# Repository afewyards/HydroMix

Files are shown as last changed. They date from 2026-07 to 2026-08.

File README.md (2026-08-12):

# ValveController

A mains-powered, Zigbee-connected controller for a hydronic **3-way mixing valve** — it
regulates the supply-water temperature of a floor heating/cooling system and keeps
regulating **autonomously** if the Zigbee link goes down.

One repo, three parts: a custom KiCad PCB (ESP32-C6), ESP-IDF firmware with a
host-testable control core, and a Zigbee2MQTT converter.

> **Status:** Firmware **1.7.0** released and OTA-deployed (2026-08-11); pure-C control core
> passes host-side unit tests; on-target bring-up of this board per
> [`firmware/BENCH_CHECKLIST.md`](firmware/BENCH_CHECKLIST.md) once assembled.
> PCB rev A — layout complete and **fab-ready** (4-layer, 100 % routed, DRC clean); boards
> ordered 2026-08-12. Personal project.

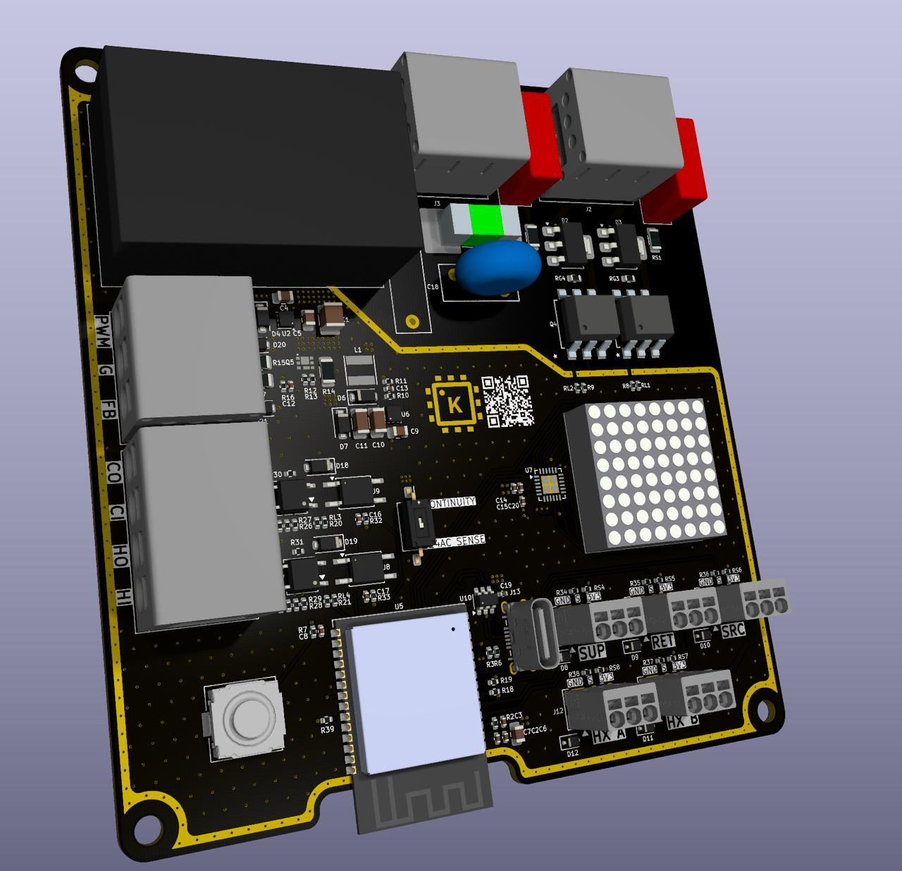
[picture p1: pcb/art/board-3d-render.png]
ValveController 3D render


## What it does

A 3-way valve mixes **SOURCE** water (the hot or cold secondary side of a heat exchanger)
with **RETURN** water from the floor loop to produce **SUPPLY** water at a target
temperature. The controller:

- **Auto-detects mode** (heating / cooling / idle) from a heat-exchanger inlet sensor — the
  host never has to tell it which season it is.
- Regulates supply temperature with a **feed-forward mixing model + PI trim**, hard-bounded
  to floor-safe limits (17–35 °C).
- Drives an ESBE ARA661 230 V 3-point actuator through two solid-state (opto-triac) channels.
- Reads **5× DS18B20** probes (supply, return, source, and two heat-exchanger points) over 1-Wire.
- Exposes everything over **Zigbee** (Router role) for monitoring, tuning, the
  regulation-enable toggle, and **OTA** — with a first-class **Home Assistant / Zigbee2MQTT**
  integration.
- **Runs fully standalone** when Zigbee is unavailable, with a supply "governor" that
  de-escalates any temperature excursion toward safe recirculation regardless of mode.

### ⚠️ The counter-intuitive safety rule

Valve position **0 % = full recirculation** (return water only — thermally harmless).
**100 % = full source** (full hot or cold). Parking the valve "closed" (100 %) would run the
floor at full source temperature and is **dangerous** — so the safe park/idle position is
**mid-travel (~50 %)**, and a resync always drives toward the 0 % end, never the source end.
See the [design spec](docs/superpowers/specs/2026-07-13-firmware-design.md) for the full rationale.

## Hardware

Custom single-board design in KiCad (`pcb/`). Rev A highlights:

| Block | Parts |
|---|---|
| MCU | **ESP32-C6-WROOM-1-N4** (RISC-V, 802.15.4 Zigbee radio, 4 MB flash) |
| Power | 230 V AC → **Mean Well IRM-03-5** (5 V) → **TLV75733** LDO (3.3 V); USB-C 5 V is diode-OR'd in (B5819W) so the board bench-powers and flashes over USB-C with **no mains** |
| Pump interface | **TPS61040** boost to 24 V, driving a **Wilo Para ST 15-7-50 iPWM2** circulator over its PWM/feedback interface |
| Valve drive | 2× channel: **MOC3063S** zero-cross opto-triac → **Z0103MN** triac, switching the 230 V 3-point actuator; RC snubbers + X2 safety caps |
| AUX outputs | 2× **CPC1035N** PhotoMOS channels (24 VAC) with **HCPL-354** loop-open/short detection |
| Mains protection | Varistor (B72210S) + fuse |
| Sensing | 5× **DS18B20** on dedicated 1-Wire connectors (4.7 k pull-ups) |
| I/O | Tactile button, 8×8 LED matrix (**KWM-20881AGB** + **IS31FL3730** driver), **USB-C** — native USB-Serial-JTAG (power, flash, console, JTAG in one port) |
| Connectors | Phoenix pluggable terminal blocks (mains in, actuator) + 5 sensor headers |

Full parts list: [`pcb/ValveController.csv`](pcb/ValveController.csv). Custom 3D component models
live in `pcb/3dmodels/`; `board.step` (repo root) is the assembled-board export.

## Firmware

ESP-IDF 5.5.x, plain C on FreeRTOS. See **[`firmware/README.md`](firmware/README.md)** for the
full build/flash/monitor guide, GPIO map, partition/OTA scheme, console commands, and gestures.

The control logic lives in a **pure-C, IDF-free component** (`firmware/components/ctrl_core/`) so
it compiles and unit-tests on the host (macOS/Linux) before any hardware is involved:

- `feedforward` — exact mixing physics, `(T_set − T_return) / (T_source − T_return)`
- `pi` — PI trim with conditional anti-windup
- `governor` — outermost safety stage; ramps toward recirculation on any supply excursion
- `mode_detect` — heating/cooling/idle with asymmetric dwell + hysteresis
- `degradation` — sensor-fault fallback ladder
- `pos_estimator`, `interlock`, `alarm`, `config_map`

The IDF-side glue (`firmware/main/`) wires that core to hardware: `sensors_hw`, `valve_hw`,
`zigbee`, `ota`, `ui`, `console`, `control_task`, `config`.

Quick start:

```bash
. ~/esp/esp-idf/export.sh
cd firmware
idf.py set-target esp32c6       # first time only
idf.py build
idf.py -p <PORT> flash monitor  # over USB-C; Ctrl+] to exit the monitor
```

Host-side control tests (plain CMake + Unity, no hardware): [`firmware/test_host/`](firmware/test_host/).

## Zigbee / Home Assistant

Router role · manufacturer `Knife` · model `HydroMix`.

- **EP1** — Basic, Identify, On/Off (`water_running` = regulation enable, driven by the host's
  pump/flow automation), Thermostat (local temp = supply; setpoints clamped 17–35 °C; mode is
  auto-detected, host `SystemMode` writes accepted-but-ignored), Analog Output (manual position,
  writable only while regulation is off), OTA client, and a manufacturer-specific cluster
  (`0xFC00`) exposing ~10 tunables, a self-clearing `resync`, and read-only alarm/fault bitmaps.
- **EP2–EP6** — Temperature Measurement for supply, return, source, HX-A, HX-B.

[`z2m/valvectl.mjs`](z2m/valvectl.mjs) is the external Zigbee2MQTT converter (friendly entity names,
tunables as settings, alarms as binary sensors, OTA index). The manufacturer OTA-publishing steps
are documented in the comment header of that file.

## Repository layout

```
ValveController/
├── pcb/                        KiCad project (schematic, board, DRC rules, BOM)
│   ├── 3dmodels/               custom STEP models
│   ├── Kleist2.pretty/         project footprint library
│   └── backups/                local pre-edit snapshots (git-ignored)
├── firmware/                   ESP-IDF application
│   ├── main/                   IDF glue (sensors, valve, zigbee, ota, ui, console)
│   ├── components/ctrl_core/   pure-C control logic (host-testable)
│   └── test_host/              Unity unit tests
├── z2m/valvectl.mjs             Zigbee2MQTT external converter
├── docs/superpowers/           design spec + implementation plan
├── analysis/                   design review reports (schematic, PCB layout)
└── board.step                  assembled-board 3D export
```

## Safety

⚠️ This board switches **230 V AC mains**. All bench work — firmware, sensor reads, triac-drive
verification — can be done on **USB-C power alone**; do not connect mains until the drive channels
are verified per [`firmware/BENCH_CHECKLIST.md`](firmware/BENCH_CHECKLIST.md). And keep the position
convention in mind: the safe idle is **mid-travel**, not "closed."

## Documentation

- [Firmware guide](firmware/README.md) — build, GPIO map, OTA, console, gestures
- [Design spec](docs/superpowers/specs/2026-07-13-firmware-design.md) — control theory, safety, Zigbee model
- [Implementation plan](docs/superpowers/plans/2026-07-13-firmware.md)
- [Bench checklist](firmware/BENCH_CHECKLIST.md)
- [Design review — schematic, 2026-08-11](analysis/design_review_2026-08-11.md)
- [Design review — PCB layout, 2026-08-12](analysis/design_review_2026-08-12_pcb.md) — fab-ready verdict; mains isolation verified against IEC 60664-1

---

Personal project by Thierry Kleist. Released under the [MIT License](LICENSE).

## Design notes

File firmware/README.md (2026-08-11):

# ValveController Firmware

ESP-IDF firmware for the ValveController PCB (ESP32-C6) — a hydronic 3-way mixing
valve controller regulating supply temperature, exposed over Zigbee (Router role)
with OTA, autonomous when the Zigbee link is down.

## 1.7.0 — one diagnostics ring, one clamp table, and `zigbee.c` split four ways

No behaviour change. This release pays down the duplication the 1.6.x debugging work
left behind, so the display/AUX board firmware has clean seams to attach to instead of
three copies of everything to keep in sync.

### Diagnostics: three hand-rolled RTC rings become one

1.6.2 through 1.6.4 added three independent RTC-RAM history mechanisms under time
pressure, one per hypothesis: the 1-Wire tally in `sensors_hw.c`, the per-task
heartbeats in `taskhb.c`, and the Zigbee attribute-write tally in `zigbee.c`. Each
reinvented the same warm/cold-boot detection, 4-deep history shift, and reset-reason
name table — with the two reset-reason tables drifting apart in the process. All three
now sit on one portable `ctrl_core/diag_ring` module (host-tested, zero ESP-IDF
dependencies), and the typed payloads each owner keeps are unchanged. The merged
reset-reason table also **gained** `efuse`, `PWR_GLITCH` and `CPU_LOCKUP`, which neither
of the two originals had. The Zigbee tally's extraction into its own `zigbee_diag.c`
(on the shared ring) was already done in the prior commit; this release is the other
two plus the consolidation.

### Config clamping: three implementations become one table

`clamp_config`, `config_apply_custom` and `tunable_apply` each re-derived the same
per-field min/max/default independently, which is exactly the kind of place a range
quietly drifts between call sites. All three now delegate to a single `SPEC[]` table in
`ctrl_core/config_map.c`, and `config_t` embeds `tunable_cfg_t` directly rather than
duplicating its fields.

`sizeof(config_t) == 76` and every field's offset are pinned by ten `_Static_assert`s,
because `config_load()` tells NVS blob versions apart **by size** — a silent size change
would make every deployed device's stored tuning unreadable and silently revert it to
defaults on next boot. The v1→v2→v3 migration path is untouched and the blob stays
byte-compatible with every device already in the field.

### `zigbee.c`: 984 lines become four files

`zigbee.c` shrinks from 984 to 411 lines, with `zigbee_attrs.c` (169 lines — the
custom-cluster write dispatch), `zigbee_telem.c` (278 lines — telemetry task and
attribute reporting) and `zigbee_diag.c` (137 lines — the write tally, extracted in an
earlier commit of this same release) taking the rest. `zigbee.c` itself keeps only
init, endpoint/cluster registration, and join/steer signal handling. Lock discipline
is unchanged: still exactly 5 `esp_zb_lock_acquire`/`release` pairs, none of them in
the attrs or diag files. This is the seam the display/AUX board's two on/off endpoints
will attach to.

### Image size

712,800 bytes, 64 bytes **smaller** than 1.6.4 (712,864), 62% of the 1.9 MB OTA slot
free either way. Flash was never the constraint here — the Zigbee stack alone is about
half the image, and all of `main/` plus `ctrl_core` together is roughly 3%. This
release traded duplicated logic for a table and a shared module; it did not chase
space, because there was no space problem to chase. (The `-Og`→`-Os` optimisation-level
change is deferred to 1.7.1 as its own single-variable release, shipped alone with
nothing else changed, since it alters code generation on a live heating plant.)

Host suite 19/19.

## 1.6.4 — the console REPL was starving the idle task

Two days of "every temperature probe is dead" were a reboot loop wearing a sensor
costume. Root cause: with no USB host attached, the console REPL's reads return
immediately instead of blocking, so its line-editing loop free-runs. It sits at a
priority above the idle task (0) and below the app tasks (4-6), so every
watchdog-subscribed app task kept feeding normally while the idle task never got
scheduled — and the idle task is a subscriber
(`CONFIG_ESP_TASK_WDT_CHECK_IDLE_TASK_CPU0=y`). 30 s later, `ESP_RST_TASK_WDT`. Forever,
every ~40 s, but **only when no USB host was attached**.

That is the whole illusion. Probes boot latched-faulted for ~30 s by design
(`SENSOR_CLEAR_AFTER` = 3 sweeps at 10 s), and the board reset at ~40 s. So the only
value that ever reached the coordinator was the ZCL invalid sentinel 0x8000 — five
simultaneously dead probes, over and over, on a plant whose probes were perfect.

`console_start()` now waits for `usb_serial_jtag_is_connected()` in a task that blocks on
`vTaskDelay` before creating the REPL. Verified live: mains-only cold boot, temperatures
flowing continuously past the 40 s mark and `mode` back to `cooling` — the plant
regulating again for the first time since 2026-08-10.

### What was innocent

Worth recording, because each was suspected in turn and none was at fault: the DS18B20
probes and the 1-Wire bus (zero read failures in every tally, ever), the temperature
attribute writes (`ok`, `mism=0`, table reading back real values), the Zigbee reporting
path, the power supply, and 1.6.1's feedforward change — which altered only mixing-law
maths and was blamed purely because the outage began at its OTA reboot. The OTA reboot
was the trigger only in the sense that it was the first boot with no USB attached.

### The observability trap, which cost more than the bug

Reaching this board's console takes two resets: plugging the cable in is one, opening the
port is another. Worse, attaching USB is *also* the intervention that stops the fault. So
a one-deep "previous run" record always describes the run your own reset ended, never the
run the fault ended — the measurement consumes its own evidence.

That trap was hit three times in one investigation: it destroyed the 1-Wire tally for the
13 h outage, then the first attribute-write tally, then the first heartbeat record. Every
RTC diagnostic now keeps **4 runs**, tagged with a boot sequence number, and where it
matters labelled with how each run ended (`boot=TASK_WDT`). Two resets can no longer reach
the run under investigation.

### Diagnostics added

- `stats` — 1-Wire failure tallies per reason (`rmt`/`reset`/`write`/`read`/`crc`/`por85`), 4 runs deep.
- `zbtemp` — per-endpoint attribute-write ok/fail/status, plus a read-back of what the ZCL
  table actually holds, with ticks/sweeps/faults and the reset reason per run.
- `hb` — per-task heartbeat ages, each run labelled by how it died. This is what named the
  culprit: every app task fed on schedule right up to the reset, leaving the idle task as
  the only possible starved subscriber.

Host suite 17/17.

## 1.6.2 — a dead sensor sweep can no longer hide as five dead probes

On 2026-08-10 the plant sat parked for 13 h after an OTA to 1.6.1. All five probe
endpoints published the ZCL invalid sentinel (0x8000) continuously from 19:11:32Z —
the moment of the post-OTA reboot — until a reset was forced by hand the next
morning. Everything else looked healthy: the device stayed joined, answered reads,
accepted valve commands, and the temperatures had been reporting normally right up
to 19:10:53Z with the plant actively cooling.

The 1-Wire bus was never the problem. `stats` after the reset showed **zero read
failures of any kind** — no `rmt`, no `reset`, no `crc`, on any probe — and every
probe returned a plausible temperature immediately.

**Superseded by 1.6.4: neither hypothesis below was right.** The outage was a
`TASK_WDT` reboot loop every ~40 s caused by the console REPL starving the idle task
whenever no USB host was attached; the probes never failed at all. The two candidates
recorded here are kept because the reasoning that produced them is instructive, not
because either was correct.

At the time the root cause was not identified, and the evidence that would have named it
was gone: the per-reason failure tally lived in RTC RAM and held only one previous run,
so plugging in the console cable to read it overwrote the very run under investigation.
Two mechanisms then looked consistent with everything observed:

- the 1-Wire/RMT driver wedged, failing every read (would have logged a `sweep N
  failed: …=rmt` line every 10 s);
- the sweep task never ran at all (would have logged nothing whatsoever).

Both were excluded once the reboot loop was found: every tally showed zero read failures
and normal sweep counts. The changes in 1.6.2 remain worth keeping on their own merits —
they close a real gap in which a dead sweep is indistinguishable from five dead probes —
but they did not fix this outage.

What made a 13 h silent outage possible is a gap that IS identified, and is fixed here.
`sensors_start()` seeds every probe latched-faulted on purpose, so a sweep task that
dies — or never starts — is indistinguishable from five simultaneously dead probes,
permanently. Nothing else caught it either: the staleness guard in
`sensors_fill_faults()` is skipped while `last_ok_ms == 0`, and a task that never ran
never subscribed to the task WDT, so the watchdog had nothing to time out on. The
plant parked, which is correct, and said nothing, which is not.

- **Sweep liveness is now tracked per iteration**, not per successful read — a sweep
  that runs and fails everything is a plant problem, one that stops running is a board
  problem, and only this separates them. Surfaced as `FAULT_BIT_SWEEP` (bit 5), so
  `fault_bitmap` reads 0x3f for a dead sweep against 0x1f for five dead probes.
- **Bounded self-heal.** 120 s of dead sweep triggers a reset, up to 3 consecutive
  attempts, after which the board stays up and parked with the bit raised rather than
  reboot-looping a live household plant. The budget is restored after 10 min of healthy
  sweeping. The counter lives in RTC RAM so it outlives the reset it is counting.
- **Every `xTaskCreate` return is now checked.** All of them were unchecked, so a
  failed create was silent and permanent — a failure mode that produces exactly the
  observed signature. The sensor, valve, control, Zigbee and telemetry tasks abort
  (panic → reset → rollback on an unvalidated image); the LED and button tasks only
  log, since taking a working plant down over a dead status LED is the larger fault.

Host suite 17/17.

## 1.6.1 — the feedforward no longer picks a rail on probe noise

Diagnosed from live GF-HydroMix history over 2026-08-07..10. The cooling plant lost
output for ~4.5 h on 08-08 (01:40–06:30Z): source, supply, return and hx_b all
equilibrated at ~21 °C and hx_a — normally the coldest point at ~15 °C — rose to
23.4 °C. With `t_src ≈ t_ret` the mixing law had no authority, and dT(return−source)
sat inside ±0.05 K for the whole window.

The feedforward computes `clamp((t_set − t_ret)/(t_src − t_ret) · 100, 0, 100)`.
`want` cannot change sign within a mode, so at low authority the sign of the
denominator alone decided which rail the output clamped to. 1.5.1 limited the
denominator's magnitude to the authority floor but kept its measured sign, which
left a step discontinuity at `denom = 0` the width of the entire output range: at
t_ret 20.9 / t_set 18.5, t_src 20.89 commanded 100 % and 20.91 commanded 0 % — two
readings 0.02 K apart, well inside DS18B20 pair-to-pair disagreement.

Live, the valve chattered rail to rail with the 180 s output EMA turning it into a
sawtooth: **2906 % of travel on 08-08 against ~750 % on each neighbouring day**, and
six end-stop resyncs between 02:34 and 09:51. Closing was also the self-defeating
move — at the measured −0.041 K/% coupling, shutting the valve drives `t_src` further
past `t_ret`, deepening the condition that closed it.

1.6.1 blends the two available answers instead of switching between them: the
measured-sign answer, and the demand direction that restores authority, weighted by
`w = |denom| / floor` and only inside the band. Where the source is on the useful
side both terms are the same expression, so the healthy operating band is unchanged
bit for bit; only near-zero readings, where the sign is noise, are reinterpreted. A
source genuinely past the floor — the unseated-probe case — still clamps to 0 %.

Continuity sweep, worst adjacent output jump per 0.05 K of probe movement: **100.00
→ 2.50**, the blend ramp's own maximum slope.

The demand-direction fallback rests on the source↔valve coupling being negative,
which is a property of the **fixed-speed pump** — valve position is the only thing
modulating source-branch flow, so starvation dominates. A pump that modulates flow
independently invalidates the premise; re-measure open-loop before carrying it over.
See `FF_COUPLING_PCT_K` in `feedforward.h`.

Known-unfixed, found in the same investigation: `travel_since_resync` is written
every 10 s by `zigbee_push_status()` and is declared reportable, but
`configure_reporting_on_join()` never arms a reporting record for it — so it only
ever reaches the coordinator on an explicit read at `configure()` time and reads
frozen in HA.

## 1.6.0 — resync can now target the source end, gated by comfort

Diagnosed from 19 h of live GF-HydroMix telemetry (16:29Z–01:47Z, 2026-08-05): in the
current cooling regime the valve regulates at 85–100 %, so every position resync —
previously always a drive to the 0 %/recirculation end-stop — was a ~200 % round trip
with ~3 min of forced recirc and a ~2 K supply excursion. Three such events tripped
in that window, preferentially right after source cold slugs, i.e. exactly when the
plant was already disturbed. "Valve goes to 0 for no reason" was the live symptom.

- **A resync may now target the 100 %-source end-stop** when the valve is already near
  it and a comfort gate passes, instead of unconditionally driving to recirc. New pure
  module `ctrl_core/resync_policy.c` decides the end each cycle:
  - position < `RESYNC_NEAR_END_PCT` (50 %) → recirc-end immediately (cheap; the mix
    is mostly recirc already).
  - position ≥ 50 % and the gate passes → source-end.
  - position ≥ 50 % and the gate fails → deferred, re-checked every control cycle:
    source-end the instant the gate passes, or recirc-end after
    `RESYNC_DEFER_MAX_MS` (30 min) — whichever comes first. Position dropping below
    50 % while deferring also forces recirc-end immediately, since it just got cheap.
  - The accumulated-travel / reversal counters that trigger a resync keep accumulating
    through deferral; they only reset on resync completion, unchanged.
- **The comfort gate** (`resync_gate_eval()`, computed once per cycle in `control_step`
  and published to `valve_hw` via `valve_note_resync_gate()`) requires: mode is HEATING
  or COOLING, the source probe is unfaulted, `|t_src − setpoint| ≤ RESYNC_SRC_GATE_K`
  (2.0 K), and `t_src` sits inside the governor band with a `RESYNC_GATE_GOV_MARGIN_K`
  (1.0 K) margin on both sides. A dew-guard-raised setpoint tightens the gate along
  with it automatically. All four thresholds are compile-time constants — no new
  Zigbee tunables.
- **Mid-stroke abort:** resync ignores regulation targets while driving, so a
  source-end stroke that starts at the edge of a cold slug can carry `t_src` below the
  governor band with nothing to stop it. If the source leaves the raw governor band
  during a source-end stroke, the stroke aborts and restarts as a fresh full
  recirc-end stroke — its stall deadline extended by the interlock's reversal
  blackout (`INTERLOCK_MIN_PULSE_MS + INTERLOCK_DEAD_TIME_MS +
  INTERLOCK_ANTI_DITHER_MS`) so the deadline accounts for the pulse-finish,
  dead-time and anti-dither the interlock imposes before the reversed drive actually
  starts. Recirc-end strokes never abort. Worst case equals pre-1.6.0 behavior; never
  worse.
- **Boot resyncs and manual resyncs (console `resync` / Z2M switch) stay forced
  recirc-end**, unconditionally — sensors boot latched-faulted, and bench use wants a
  predictable end-stop. A manual resync requested while an autonomous source-end
  stroke is already driving is **latched, not dropped**: `valve_task` only consumes
  the pending manual-resync flag once the drive returns to idle, so it fires as a
  forced recirc-end stroke the moment the in-flight autonomous stroke completes.
- Stroke duration stays `travel_time_s × RESYNC_STALL_MULT` in both directions (plus
  the abort extension above) — drift is why a resync happens at all, so no
  distance-based shortening. `pos_est_resync_done()` now takes the end-stop seed (0.0
  recirc / 100.0 source) instead of always seeding 0.
- This deliberately supersedes the 2026-07-13 "resync only toward the
  0 %/recirculation end-stop" rule and the `NEVER toward source` comment it left in
  `valve_hw.c`. The original rationale — 100 % source is the dangerous end — now
  holds via the gate, the governor-band bound and the mid-stroke abort, not a blanket
  prohibition.
- Not yet Zigbee-exposed: resync events, the chosen end, and gate state publish
  nowhere — pairs with the still-open `ff.frozen`/authority-floor telemetry gap from
  1.5.1, next release.

New constants (`components/ctrl_core/include/ctrl_core/resync_policy.h`):
`RESYNC_SRC_GATE_K` 2.0 K, `RESYNC_GATE_GOV_MARGIN_K` 1.0 K, `RESYNC_DEFER_MAX_MS`
1 800 000 (30 min), `RESYNC_NEAR_END_PCT` 50.0 %.

Design spec: `docs/superpowers/specs/2026-08-05-gated-bidirectional-resync-design.md`.

Suite 17/17, 119 tests. Build clean, 63 % OTA headroom, embedded app version verified
1.6.0.

## 1.5.1 — the authority floor had the wrong sign, and the freeze latched the valve

**1.5.0 broke cooling on the live plant.** On 2026-08-04 the valve sat at 55.7 % for 92
minutes while supply ran 2.6–2.75 K above an 18.5 °C setpoint and the house stopped being
cooled. Root-caused from 869 Z2M samples (09:00–10:33).

### What went wrong

Three things compounded:

1. **A freeze disconnected the whole controller, not just the integrator.** `pi.c`'s
   `if (freeze) return ctrl_clampf(pos_ff, …)` discards **both** P and I, and `control.c`
   passed `freeze_pi || ff.frozen`. So a low-authority FF handed the valve a bare frozen
   constant and ran open-loop — while `t_supply`, a perfectly valid measurement, was ignored.
2. **The floor was placed inside the plant's normal operating range.** At the live 18.5 °C
   setpoint the derived floor was `sqrt(2.7·100·0.065)` = 4.19, clamped to the 4.0 K ceiling.
   Measured `|t_src − t_ret|` runs **0.07–4.75 K, mean 1.89** → **87 % of samples treated as
   no-authority.** The valve moved on exactly 5 occasions in 92 min, *all* of them inside the
   one window where `|denom|` crossed 4.00.
3. **The escape hatch was a no-op.** `if (ff.park_requested) target = in->valve_pos;` commands
   exactly what the freeze already commands. 1.5.0 correctly identified that the old open-loop
   park to `park_pos` was harmful, but deleted the only thing that broke the latch.

And the latch is self-reinforcing: a pinned valve starves the source branch, a starved branch
stops being cooled, `t_src` drifts toward `t_ret`, `|denom|` shrinks further. It reached
**0.07 K**. There was no exit.

### The coupling sign was inverted

`FF_COUPLING_PCT_K = +0.0654 K/%` came from a 20 h **closed-loop** fit at only r = +0.49,
taken while the HX primary itself drifted 14.25 → 16.93 °C. The controller opens the valve
*because* the primary warmed, so valve % and `t_source` both track `hx_a` and correlate
positively with no causal content — a confound.

The open-loop measurement (valve held manually at full source, primary flat to within
0.19 K) gives the **opposite** sign: `t_src` fell 20.87 → 19.06 °C over ~44 % of travel,
about **−0.041 K/%**. More source flow *cools* the source; flow starvation dominates the
textbook rise in HX approach.

That inverts the derivation, not just its magnitude. `ff_authority_floor()` computes a loop
gain **magnitude** and treats |G| > 1 as runaway — but sign decides whether feedback
diverges. With the true negative coupling, opening the valve cools the source, *grows*
`|denom|` and backs the valve off: negative feedback, self-limiting. **The floor guarded a
runaway that cannot happen in this plant, while manufacturing a real latch.**

### The fix

- **`ff_step` now LIMITS the denominator instead of abandoning the division.** Output stays
  live, bounded, continuous and correctly signed, and — because the coupling is negative — it
  points the valve the way that *restores* authority. Saturating toward the source is the
  correct response to a converging source, not an error to suppress. A source on the wrong
  side of `t_ret` still clamps to 0; `denom == 0` falls back to the demand direction.
- **`ff.frozen` no longer freezes the PI.** Only `resync_active` does, where the valve is
  being driven to an end stop and the output is moot anyway.
- **`FF_COUPLING_PCT_K` → 0**, so the floor is a fixed 2 K numerical guard. Do *not* re-enable
  it from another closed-loop fit — it needs an open-loop step test (park the valve at 2–3
  positions ≥ 20 min each with the controller out of the loop).
- **`FF_OUT_TAU_S` 900 → 180 s.** 900 s was ~7.5× the valve travel time. The travel reduction
  it was credited with came mostly from the freeze pinning the valve: at 180 s the 1.5.0 sim
  is still frozen 100 % of the time with zero travel.
- **`park_requested` / `FF_NO_AUTHORITY_PARK_DWELL_MS` removed**, along with `last_valid` /
  `freezing` / `frozen_since_ms` — all dead once the denominator is limited. `water_running`
  OFF, `MODE_IDLE` and `CTRL_PARK` parks are untouched; those are real safety parks.

### The test that blessed the bug

`test_hx_feedback.c`'s headline gate was `new.travel < 0.50 × old.travel` — *"the valve moved
less."* Re-run on its own plant at the shipped coupling, 1.5.0 gives **travel 0.0 %, frozen
100 %, pinned at 48.3 %, supply 1.0 K warm — and it PASSED.** Its supply guards passed only
because the baseline it compared against was itself railed at 98.3 % with +2.65 K error.

**A latched valve trivially wins a travel-reduction gate.** Travel is now bounded on *both*
sides and tracking error is capped absolutely, not relative to a broken baseline. The plant
also carries the measured negative sign, and `test_ff_recovery.c` is new: it starts in the
observed starved state and fails on 1.5.0 (49.2 %, travel 0, +2.33 K) while 1.5.1 reaches
95.8 % — the analytic optimum is 95.7 % — at −0.01 K.

Suite 16/16, 105 tests. Build clean, 63 % OTA headroom, embedded app version verified 1.5.1.
Flashed over USB 2026-08-04. **Still open:** `ff.frozen` and `authority_floor_k` are published
nowhere, which is why 87 % frozen was invisible in HA and a human had to notice the house was
warm. Exposing them needs a Zigbee attribute plus a converter deploy — next release.

## 1.5.0 — feedforward vs. the HX approach coupling; no more open-loop parks

Diagnosed from 20 h of live GF-HydroMix cooling telemetry (2026-08-03), after the valve
began hunting once the cooling setpoint moved from 20 °C toward 19 °C.

> **Version note.** The 2026-08-03 bench build shipped everything below but still
> self-identified as **1.4.0**, because `version.txt` was never bumped — a different
> failure from the 1.3.x `PROJECT_VER` CMake-cache trap, with the same symptom. When you
> need to know which source a flashed image really is, check for a version-unique symbol
> (`nm build/valvecontroller.elf | grep ff_authority_floor`) rather than trusting the
> reported version, `version.txt`, or Z2M's `installed_version`.

### The 60 s park was worse than the freeze it escalated (2026-08-04)

Live follow-up on the build above: the valve kept dropping to ~22 % for ~90 s at a time.
Not a spike and not a reporting artefact — a *commanded* move, every step exactly
8.3 %/10 s (full slew at `travel_time_s 120`), bottoming just short of `park_pos 20`
because `valve_deadband_pct 2` stops the motor within 2 % of target.

- **Cause: the derived floor made the freeze reachable, and the freeze escalated to a
  park.** The floor tracks the setpoint, so moving from 20 °C to 19 °C raised it from
  2.79 K to **3.51 K** (at `t_ret ≈ 20.9`), while the plant's live `|t_src − t_ret|` runs
  3.31…6.75 K — it dips under 3.51 K but never under the old fixed 2.0 K. Replaying the
  freeze predicate over 3 h 13 m of telemetry: **exactly two freezes ≥ the 60 s dwell,
  exactly two observed parks, zero false positives in 2316 samples.** So the fix for
  hunting at 19 °C is what introduced parking at 19 °C.
- **`park_requested` now holds position instead of driving `park_pos`, and no longer
  resets the PI.** Parking is open-loop, and in cooling it *raises* supply temp (+0.7 K
  measured per event) — it manufactures the disturbance the loop then has to undo. A
  freeze is already stable on its own: the FF holds `last_valid`. Recovery from a hold
  resumes on the integrator it left, rather than rebuilding from zero.
- **`FF_NO_AUTHORITY_PARK_DWELL_MS` 60 s → 600 s**, demoted to a backstop for a genuinely
  stuck plant now that the sustained case no longer parks.
- The `water_running` OFF, `MODE_IDLE`, and `CTRL_PARK` degradation parks are unchanged —
  those are real safety parks. The governor still applies after the hold.

### Investigated and REJECTED: splitting the PI deadband off the integral path

Supply sits at **+0.39 K** against a 19 °C setpoint (user-visible as "19.5 instead of
19"); the parks above account for only +0.025 K of it. `pi_step()` zeroes `e_eff` inside
±`deadband_k` and uses it for **both** the proportional and integral paths, so on paper
every point in `[setpoint − deadband_k, setpoint + deadband_k]` is an equilibrium with a
frozen integrator — a textbook permanent offset. The live minimum over a 3 h capture was
exactly **18.75** = 19 − 0.25, sitting precisely on the deadband edge, with 52 % of
samples inside the band. That looked conclusive.

**It did not survive simulation, and the change was reverted.** `test_lagsim`'s FOPDT
loop, 6 h per run, comparing the shipped code against a variant whose integrator runs on
true error, plus two intermediate variants (integral deadband at 0.4× and 0.6× the
proportional one):

- At **4 of the 5 corners the offset is identical to three decimal places** across every
  variant and every `ki` in 0.9…0.2. The residual offsets there (+0.17, −0.50, +0.17,
  −0.05) are plant and valve-quantisation artifacts the integral path cannot influence.
- At **θ=40 / τ=60 removing the integral deadband is materially worse**: the loop settles
  at **−0.94 K** where the shipped code sits at **+0.06 K**. That is integral windup
  through the 40 s deadtime — the deadband is acting as a brake against it, not merely
  buying the offset. This is the corner closest to the real GF-HydroMix plant.
- It also breaks the existing `new_pp < 0.8` gate at the shipped `ki=0.9` (1.21 K) and
  would have needed a `ki` retune to 0.5 purely to compensate.

Why the live signature misleads: in the lagsim's geometry (`T_SRC` 45 / `T_RET` 27, an
18 K span) 2 % of valve travel is worth ~0.54 K of supply, which swamps the 0.25 K
deadband. On the real plant the span is only ~4.8 K, so 2 % of travel is ~0.13 K and the
deadband edge becomes visible in the data — but visible is not the same as binding, and
no variant of relaxing it actually moved the number.

**If the offset is worth chasing, do it with the existing `pi_deadband_k` tunable
(custom-cluster 0x000F, live-writable over Zigbee) as a reversible experiment on the real
plant — not with a structural change to the controller.** Note the 1.4.0 five-corner
sweep already found ripple *non-monotonic* in `pi_deadband_k` between 0.15 and 0.25
(limit-cycle regime hopping), so do not bisect it; test discrete values and watch.

- **The FF was driving its own denominator.** `ff_step()` inverts a mixing law that treats
  `t_source` as an independent input. On a plate HX fed by a fixed primary it is not:
  opening the mixing valve raises *secondary* flow, collapses the HX approach, and warms
  `t_source` — the quantity `pos_ff = (t_set − t_ret)/(t_src − t_ret)` divides by.
  Regressed live: **d(t_source)/d(valve %) = +0.0654 K/%** (r = +0.49), approach sweeping
  −0.57…+6.25 K while the primary side (`hx_a`) stayed inside 14.25…16.93 °C. Net effect:
  `t_source` swung **7.81 K p2p, 3× its own primary**, and the valve swung 98.5 % p2p.
  Supply itself was never the problem (sd 0.37 K) — valve travel was.
- **Authority floor is now derived from the setpoint** instead of the fixed
  `FF_MIN_AUTHORITY_K 2.0`. Chaining the coupling through the mixing law gives loop gain
  `G = |t_ret − t_set| · 100 · coupling / denom²`, so `G = 1` at
  `denom = sqrt(|t_ret − t_set| · 100 · coupling)`. That tracks the setpoint, which is
  exactly what a constant gets wrong: at `t_ret ≈ 21.2` the floor is **2.80 K at a 20 °C
  setpoint but 3.79 K at 19 °C**. Clamped to `[FF_AUTHORITY_MIN_K 2.0,
  FF_AUTHORITY_MAX_K 4.0]` — past ~4 K the freeze stops being free (measured share of
  flowing time spent frozen: 2.0 K → 3.0 %, 2.8 K → 3.6 %, 3.8 K → 6.4 %, but
  4.6 K → 17.7 % in runs long enough for the 60 s park dwell to dominate).
- **The FF output carries a 900 s EMA** (`FF_OUT_TAU_S`), applied to `pos_ff`, *not* to
  `t_source`/`t_return`. The mixing law divides by `(t_src − t_ret)`, so filtering the
  inputs and then dividing does not land where dividing and then filtering does — and
  with the denominator swinging several K that gap is not second-order. Filtering after
  the division also leaves the low-authority test on the live reading, so a collapse in
  authority is still caught the instant it happens. This is the *secondary* fix: the
  floor is what keeps the FF out of the region where it fights itself; the EMA only stops
  the motor chasing the ripple that remains.
- **A zeroed `ff_cfg_t` degrades to the pre-1.5.0 fixed 2 K floor, not to no floor.**
  `control_cfg_t` is brace-initialised in several places (including `test_control.c`), and
  a zero `auth_max_k` would otherwise disable the low-authority freeze altogether.
- `ff_reseed()` on a resync falling edge drops the output filter but keeps `last_valid`;
  `ff_mode_change()` drops both, since heating and cooling put `pos_ff` on opposite sides
  of `t_ret`.
- Not Zigbee tunables. They live in `ff_cfg_t` (filled by `ff_cfg_defaults()` in
  `control_task.c`) purely so the host tests can drive old and new behaviour through one
  code path — and so promoting any of them to a custom-cluster attribute later is a small
  diff. **No NVS bump**, so no downgrade hazard this time.

`test_hx_feedback.c` is the new closed-loop regression: the plant reproduces the measured
coupling, and the coefficient is swept {0.04, 0.0654, 0.09} because 0.0654 is a
closed-loop estimate at only r = 0.49. Across that sweep, valve travel falls to
**0.28–0.39×** and source p2p to **0.40–0.51×**, while supply p2p and mean offset improve
at the two stiffer couplings. `test_lagsim.c` is unaffected by construction — its source,
return and setpoint are constant, so the EMA reseeds on the first step and then holds.

## 1.4.0 — valve deadband tunable + RunningMode push

- **Motor stop deadband is now a runtime Zigbee tunable** (`0x0012 valve_deadband_pct`,
  float %, custom cluster `0xFC00`, same read/write/NVS-persist machinery as the other
  tunables). Was a compile-time `#define DEADBAND_PCT 2.0f` in `valve_hw.c`.
  **BEHAVIOR CHANGE:** the shipped default is now 1.0 % *at `travel_time_s` ≥ 120 s*
  (was effectively 2.0 % on every device before this release, regardless of
  `travel_time_s`) — halved because at `kp=2.8 %/K` that's ≈±0.36 K of supply error
  before the motor reacts, and the existing 30 s transit hold + 0.25 K supply-move
  release already suppress oscillation at the tighter band. Below `travel_time_s=120`
  this is NOT a straight halving: `clamp_config()` raises the migrated default up to
  the travel-derived floor (below), so a device already tuned to `travel_time_s=60`
  lands at 2.0 % (unchanged) and one at `travel_time_s=30` lands at 4.0 % (doubled).
  Clamped to `[max(0.2, floor), 5.0]`, where `floor` is derived from the interlock's
  minimum drive pulse and the current `travel_time_s` (`1.2 × (INTERLOCK_MIN_PULSE_MS /
  1000) × 100 / (2 × travel_time_s)` — ≈1.0 % at 120 s, 2.0 % at 60 s, 0.2 % at 600 s):
  a constant floor below this lets a short travel time turn every drive pulse into a
  full band crossing, limit-cycling the motor. Writing `travel_time_s` re-clamps
  `valve_deadband_pct` against the new floor as a side effect (shortening travel can
  raise the floor above an already-set deadband) — both the Zigbee attribute store and
  NVS reflect the adjusted value.
- **`pi_deadband_k` (`0x000F`) stays at its 0.25 K default.** A lower value (0.15) was
  considered alongside the valve-deadband work above, but a closed-loop sweep of
  {0.15, 0.20, 0.22, 0.25} against `test_lagsim.c`'s dead-time/lag robustness matrix
  found only 0.25 clears every corner's convergence/ripple gate — 0.25 ships unchanged.
- **NVS config migrates v2 → v3** (`CONFIG_VERSION` 2 → 3) to add `valve_deadband_pct`
  without wiping existing tunables: a 1.3.x-sized blob is read field-by-field, the new
  field defaults to 1.0, and the blob is re-saved at the new size/version. **Downgrading
  to ≤1.3.1 after this release wipes the config** — the old firmware's loader only
  recognizes its own (smaller) blob size and falls back to defaults for anything else.
- **Thermostat `RunningMode` (`0x001E`) now pushes an explicit unsolicited report** on
  every change, and once on every (re)join. This is a belt-and-suspenders addition, NOT
  the root-cause fix for the 6 h-stale `mode` sensor observed live: the actual cause was
  that EP1's `hvacThermostat` cluster was never bound in the first place (live
  binding-table inspection showed EP1 bound for `genOnOff`/`genAnalogOutput` only), so
  neither the passive ZCL reporting-engine config *nor* this new explicit push has
  anywhere to send a report without a binding. The root-cause fix is converter-side —
  `z2m/valvectl.mjs`'s `configure()` now binds `hvacThermostat` — and this firmware push
  only helps once that binding exists.

## 1.3.1 — Zigbee-writable setpoints

- **heat_setpoint / cool_setpoint moved to the custom cluster** (attrs `0x0010`/`0x0011`,
  float °C, clamped 17–35, NaN-rejected, echoed back, NVS-persisted — same machinery as
  the other tunables). The standard Thermostat cluster rejects every setpoint write on
  this device with `INVALID_VALUE`: ZBOSS enforces the ZCL single-zone invariant
  `heat ≤ cool − deadband`, which the device's independent seasonal targets (heat 35 /
  cool 18) deliberately violate. The thermostat cluster's `OccupiedHeating/CoolingSetpoint`
  are effectively static boot defaults: the firmware attempts a mirror write on every
  custom-cluster setpoint change, but ZBOSS vetoes local thermostat setpoint stores under
  the same deadband rule (verified on-air 2026-07-31, `check=false` notwithstanding), so
  reads of the standard attributes do NOT reflect the live targets — use the custom
  attrs. `z2m/valvectl.mjs` exposes both as `heat_setpoint` / `cool_setpoint` numbers
  and no longer attempts thermostat-cluster writes.

## 1.3.0 — review-findings release

Safety and correctness fixes from the 2026-07-31 firmware review:

- **water_running now survives a reboot.** Persisted in its own NVS key (`valvectl/water`,
  outside the cfg blob, so no `CONFIG_VERSION` bump) and used to seed the OnOff attribute
  at endpoint build. Previously every boot forced regulation ON while HA read OFF. Absent
  key ⇒ OFF (parks at `park_pos`). A factory reset therefore boots OFF.
- **Faulted probes publish the ZCL invalid sentinel `0x8000`** instead of a frozen
  last-good value, on both Temperature Measurement `MeasuredValue` and Thermostat
  `LocalTemperature`. `z2m/valvectl.mjs` maps it to `null`.
- **The sensor sweep is watchdogged**, and any reading older than 35 s (3 sweep periods
  + slack) is reported faulted regardless of latch state — a wedged sweep now degrades
  control to park instead of integrating frozen data. `sensors_fill_faults()` takes one
  coherent locked snapshot.
- **OTA validation gate moved outside the watchdog window:** 12 control cycles (~110 s)
  instead of 3 (~20 s), extracted to `ctrl_core/ota_gate.c` and host-tested.
- **Fault-streak decay requires 3 consecutive good reads** (break-even 25 % failure rate,
  was 33 %) — a probe failing a third of its sweeps now latches.
- **Thermostat setpoint writes echo the clamped value back** to the attribute store, and
  only write NVS when the value actually changed.
- **Cooling dew guard triggers on 30 min of traffic silence** rather than a ZDO link-down
  signal, which a silently dead coordinator never sends.
- **Supply freeze alarm is held while the supply probe is faulted** (no false latch on a
  BSS-zero reading, no false clear on a frozen in-band one).
- `travel_time_s` is latched with `direction_swap`, so a mid-stroke write cannot corrupt
  the position estimate; a short first OTA payload block now aborts loudly.

## Prerequisites

- **ESP-IDF v5.5.4**, installed at `~/esp/esp-idf` on this machine. Activate it in
  every new shell before running `idf.py`:
  ```
  . ~/esp/esp-idf/export.sh
  ```
- Target chip: **esp32c6**. If starting from a clean checkout (or after switching
  IDF versions), set the target once:
  ```
  cd firmware
  idf.py set-target esp32c6
  ```
- USB-C cable to the board's native USB-Serial-JTAG port (GPIO12/13) — this is
  used for flashing, the console, and JTAG. **No separate USB-to-serial adapter
  needed.**

## Build / flash / monitor

```
cd firmware
idf.py build
idf.py -p <PORT> flash monitor
```

The first `idf.py build` (or any build after an `idf_component.yml` change)
fetches managed components (`espressif/onewire_bus`, `espressif/esp-zigbee-lib`,
`espressif/esp-zboss-lib`) — this can take a few minutes and needs network
access. Resolved versions are pinned in `firmware/dependencies.lock` (currently
esp-zigbee-lib 1.6.8, esp-zboss-lib 1.6.4, onewire_bus 1.1.1).

Exit the serial monitor with `Ctrl+]`.

## Partition table and OTA

`firmware/partitions.csv` (4 MB flash, `CONFIG_ESPTOOLPY_FLASHSIZE_4MB=y`):

| Name | Type | SubType | Offset | Size |
|---|---|---|---|---|
| `nvs` | data | nvs | 0x9000 | 0x6000 |
| `otadata` | data | ota | 0xf000 | 0x2000 |
| `phy_init` | data | phy | 0x11000 | 0x1000 |
| `ota_0` | app | ota_0 | 0x20000 | 0x1D0000 (~1.81 MB) |
| `ota_1` | app | ota_1 | 0x1F0000 | 0x1D0000 (~1.81 MB) |
| `zb_storage` | data | fat | 0x3C0000 | 0x38000 |
| `zb_fct` | data | fat | 0x3F8000 | 0x1000 |

(Note: the OTA-data partition is named `otadata`, not `ota_data`.)

Two-slot OTA with `CONFIG_BOOTLOADER_APP_ROLLBACK_ENABLE=y`. The actual gating
logic lives in `firmware/main/ota.c`:

- On boot, `ota_init()` checks whether the running image is still
  `ESP_OTA_IMG_PENDING_VERIFY` (i.e. it was just flashed via OTA and hasn't been
  validated yet).
- The image is marked valid — cancelling any pending rollback — once
  `ota_note_joined()` (Zigbee rejoined, called from `zigbee_on_join()` in
  `app_main.c`) **and** `ota_note_good_sweep()` have both fired.
  `ota_note_good_sweep()` is called from `control_task.c` on either of:
  1. a control cycle completing with no sensor faults, checked every cycle
     (fast path), or
  2. `OTA_GATE_CYCLES` (12) completed control cycles regardless of sensor faults —
     sensor faults are a plant-wiring property, not an image property. 12 cycles at
     the 10 s control period is ~110 s, deliberately **longer** than the 30 s task
     watchdog timeout (`CONFIG_ESP_TASK_WDT_TIMEOUT_S=30`, panic on): a control task
     that hangs trips the watchdog and reboots — rolling back — *before* this gate
     could ever validate the image. (1.2.1 used 3 cycles ≈ 20 s, which fired inside
     the watchdog window and so proved nothing.)

  As a last resort, a bounded 10-minute fallback timer (started at rejoin)
  validates unconditionally if neither path above has fired yet.

  If the new image never reaches validation by any of these paths, the
  bootloader rolls back to the previous image on the next reset.

**Publishing an OTA update via Zigbee2MQTT:** there is no cloud OTA index entry
for this private manufacturer code. The process (documented in comments at the
top of `z2m/valvectl.mjs`) is: build `firmware/build/valvecontroller.bin` →
wrap it into a Zigbee OTA image (`.ota`) with the ZCL OTA header (manufacturer
code, image type, file version) → host the `.ota` file somewhere Z2M can read
it → add an entry (`modelId`, `url`, `fileVersion`) to Z2M's local OTA index
config.

## Boot-safety invariant

`triacs_safe_low()` is the **literal first statement** in `app_main()`
(`firmware/main/app_main.c`) — before NVS, before anything else. It configures
GPIO2 and GPIO3 as outputs with pull-downs enabled and immediately drives both
low. `valve_hw.c` is the **sole owner** of GPIO2/3 afterwards, and the
`ctrl_core` interlock (`interlock_step()`) guarantees the two are never driven
high simultaneously. On reset/panic/brownout/watchdog, GPIO2/3 float low
(external pull-downs + MOC3063 input threshold hold the triacs off) until
`app_main` re-establishes the safe-low state, and every boot runs a resync
toward the recirculation end.

## Hardware / GPIO map

| Function | GPIO | Notes |
|---|---|---|
| Valve open triac | GPIO2 | active-high, output-low first, owned by `valve_hw.c` |
| Valve close triac | GPIO3 | active-high, output-low first, owned by `valve_hw.c` |
| TEMP_SUPPLY | GPIO0 | DS18B20, unfiltered (PI input) |
| TEMP_RETURN | GPIO1 | DS18B20, EMA-filtered (τ≈40 s) |
| TEMP_SOURCE | GPIO10 | DS18B20, EMA-filtered (τ≈40 s) |
| TEMP_HX_A | GPIO18 | DS18B20, mode detection |
| TEMP_HX_B | GPIO19 | DS18B20, monitoring only |
| Button | GPIO9 | active-low, pull-up; short = Zigbee steering, hold ≥5 s = leave + factory reset |
| Console / flash / JTAG | GPIO12/13 | native USB-Serial-JTAG (USB-C), no separate config needed |
| *(spare)* | GPIO15 | Unconnected. Nominally the JTAG-source strap, but ignored while `JTAG_SEL_ENABLE` is unburned (the default), so the C6 always uses the USB Serial/JTAG controller. One of only two free non-strapping pins, along with GPIO16. **If you ever burn `JTAG_SEL_ENABLE`, this pin must be pulled high externally** — the C6 has no internal pull here, and a floating strap could divert JTAG to the MTDI/MTCK/MTMS/MTDO pads |

## Display: driver-output → panel mapping

The IS31FL3730's outputs are **not** wired straight through to the KWM-20881AGB.
The panel's pinout interleaves rows and columns down both of its edges, so a
straight-through wiring produced an unroutable ratsnest (40 crossings). The
outputs were permuted to make the fan-out planar (6 crossings). Rows were only
ever swapped with rows and columns with columns — the driver sources on rows and
the panel is common-row-anode, so the two groups cannot be interchanged.

**The display driver must undo this in the framebuffer.** To light the LED at
panel (row *r*, column *c*), set the bit at driver output (R, C):

| Panel row | Driver | | Panel col | Driver |
|---|---|---|---|---|
| ROW1 | **R3** | | COL1 | **C3** |
| ROW2 | **R1** | | COL2 | **C6** |
| ROW3 | **R4** | | COL3 | **C7** |
| ROW4 | **R2** | | COL4 | **C1** |
| ROW5 | **R8** | | COL5 | **C8** |
| ROW6 | **R5** | | COL6 | **C2** |
| ROW7 | **R7** | | COL7 | **C4** |
| ROW8 | **R6** | | COL8 | **C5** |

Net names follow the **driver** side: `DISP_R3` is the driver's R3 output, which
lands on panel ROW8. Two constant lookup tables in the display driver are enough;
there is no runtime cost beyond the indirection.

## Sensor sweep (`firmware/main/sensors_hw.c`)

Pipelined 1-Wire sweep every **10 s** (`SWEEP_PERIOD_MS`), sharing the C6's
limited RMT TX/RX pairs across all 5 GPIOs by creating and deleting a bus per
GPIO per phase:

1. **Phase 1** — for each of the 5 GPIOs: create bus → Skip ROM + Convert T →
   delete bus (line released; DS18B20s are externally powered so conversion
   continues unattended).
2. One shared `750 ms` delay (`CONVERT_MS`) for conversion to finish.
3. **Phase 2** — for each GPIO: create bus → read scratchpad (with CRC-8 check
   via `onewire_crc8()` from the `onewire_bus` component's `onewire_crc.h`) →
   delete bus, up to **3 retries** (`MAX_RETRY`) on failure.
4. Sleep for the remainder of the 10 s period, then repeat.

A sensor is marked **faulted** after **3 consecutive** failed sweeps
(`FAULT_AFTER`). Source and return readings are EMA-filtered with τ≈40 s
(α ≈ 0.2 at a 10 s sample period); supply is left unfiltered for the PI loop.

## Console commands (USB-Serial-JTAG, prompt `valvectl>`)

| Command | Effect |
|---|---|
| `status` | Print supply/return/source/HX-A/HX-B readings and fault flags |
| `valve <0-100>` | Manually set the valve target position (percent) |
| `resync` | Force a valve position resync |
| `mode` | Print detected mode, alarm state, fault bitmap, and position |
| `factory-reset` | Zigbee leave + NVS wipe (defaults reload on next boot) |

## Zigbee join / factory-reset gestures

- **Short button press** (GPIO9) → network steering (join).
- **Hold ≥5 s** → Zigbee leave + factory reset (NVS erased, defaults reload).

**Status indication.** The single status LED was removed from the board once the
8×8 matrix landed; local state now belongs to the display. The matrix driver is
not written yet, so until it is, the USB-Serial-JTAG console is the only local
readout — `status` and `mode` report everything the LED used to encode.

`ui.c` still contains the old `led_task` driving GPIO15. It is inert (the LED is
gone) and harmless — the pin only sees the 10 k strap pull-up, and the strapping
latch is sampled at Chip Reset, so runtime toggling cannot affect JTAG selection.
It gets replaced wholesale by the display work.

## Zigbee endpoints

Router role. Manufacturer `Knife`, model `HydroMix`. Manufacturer code is
currently `VALVECTL_MFR_CODE 0x1234` — a **placeholder/test value**, not a
real Zigbee Alliance-assigned code (see the plan's "Unresolved Q1").

- **EP1**: Basic, Identify, On/Off (`water_running`), Thermostat (local temp =
  supply; setpoints clamped 17–35 °C; `SystemMode` writes accepted but
  ignored — mode is auto-detected from HX-A; `RunningMode` pushes an explicit
  unsolicited report on change and on every (re)join, since **1.4.0**), Analog
  Output (position 0–100 %, writable only while `water_running` is OFF), OTA
  client, plus a manufacturer-specific custom cluster `0xFC00` exposing 15
  read-write tunables — including, since **1.1.0**, `0x000E deadtime_s` (transit
  hold: seconds the PI loop pauses after the valve moves, 0–120, default 30) and
  `0x000F pi_deadband_k` (PI error deadband, K, 0–1, default 0.25) — and since
  **1.4.0**, `0x0012 valve_deadband_pct` (motor stop
  deadband, % of travel, default 1.0, clamped to `[max(0.2, floor), 5.0]` where
  `floor` tracks `travel_time_s` — see the 1.4.0 notes above) — a self-clearing
  `resync` bool, and read-only alarm-bitmap / fault-bitmap / travel-since-resync
  attributes. `ki` is also %/K per **minute** as of
  1.1.0 (was %/K per 10 s cycle in ≤1.0.7); a device upgrading from an older
  build migrates its stored config automatically on first boot (ki ×6,
  clamped to the new bounds — see `config_load()` in `firmware/main/config.c`).
  Alarm and fault bitmaps report **immediately** on change (no periodic cap);
  temperatures report at ±0.2 K or 60 s max; position reports at ±1 % or
  60 s max.
- **EP2–EP6**: Temperature Measurement (supply, return, source, HX-A, HX-B).

## Zigbee2MQTT integration

`z2m/valvectl.mjs` is the external converter. See the comments at the top of
that file for the manual OTA-image publishing process referenced above.

## Host-side control-logic tests

See `firmware/test_host/README.md` — the `ctrl_core` component (pure C, no IDF
includes) is unit-tested on macOS/Linux with plain CMake + Unity before any
hardware is touched.

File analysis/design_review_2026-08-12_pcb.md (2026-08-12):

# ValveController PCB Layout Review — 2026-08-12

**Project:** pcb/ValveController.kicad_pcb (KiCad 9, 4-layer, 94.5 × 99.75 × 1.6 mm) — 124 footprints (102 SMD / 15 THT + art), 99 copper nets, 585 vias, routing 100 % complete
**Scope:** Layout-focused full review — the counterpart to the 2026-08-11 schematic review, which explicitly deferred the layout ("re-run after routing completes"). Schematic re-analyzed for regressions only.
**Assembly context (owner-confirmed 2026-08-12):** hand reflow, components placed under microscope — no machine assembly.
**Analyzers run:** analyze_schematic.py, analyze_pcb.py --full --proximity, cross_analysis.py, analyze_emc.py, analyze_gerbers.py (fresh export, same-minute as board save), kicad-cli pcb drc --severity-all (with project .kicad_dru), lifecycle_audit.py. Runs `2026-08-12_1858` / `2026-08-12_1858-2`.
**Not run:** SPICE (no simulator installed), analyze_thermal.py produced no data (no datasheet extraction cache — skipped itself), deep_review_gate.py (layout findings kept in report format; the per-IC datasheet deep review was completed 2026-08-11 and the schematic is unchanged apart from the verified fix sweep).

## Overview

Same system as the schematic review: 230 VAC-fed ESBE ARA661 valve controller (IRM-03-5 → TLV75733 3V3 → ESP32-C6; TPS61040 24 V boost for the Wilo iPWM2 pump; two triac valve channels; two AUX PhotoMOS channels; five DS18B20 probes; USB-C debug; 8×8 display). The board is now fully routed on 4 layers: **In1 = solid GND plane, In2 = 3V3 plane (86 % fill)**, mains section in the top band with a deliberate plane void, logic in the bottom two-thirds.

## Verdict

**One pre-fab blocker: G1's copper logo is parked 55 mm off the board and was exported into the gerbers.** Fix that (plus two cheap thermal-via items on U2 and U7) and this layout is ready to order. The safety-critical part — mains isolation — is genuinely well executed: a documented custom rule file enforces 6.4 mm reinforced HV↔LV spacing through complete netclass coverage, native DRC passes it with zero clearance violations, and a raw-file sample of the In1 plane confirms the mains region contains no logic copper at all. All six fixes from the 2026-08-11 schematic review are confirmed present in copper.

## Critical Findings

| Severity | Issue | Detail |
|---|---|---|
| CRITICAL (pre-fab) | **B1. G1 off-board copper is in the exported gerbers** | G1 (`KleistLabs_Logo_10mm_Copper`) sits at (5, 5) — the outline starts at x = 60.5. F.Cu gerber extents are 154.6 mm vs 94.5 mm Edge.Cuts (gerber analyzer GR-002: "width varies by 60.9 mm"). The 10 mm footprint variant also no longer exists in Kleist2.pretty (DRC `lib_footprint_issues`); the on-board art is now the 8 mm logo + QR pair. **Fix: delete G1 from board and schematic (or place it properly), refill zones, re-export gerbers.** Raw-file + gerber verified. |
| WARNING | **W1. U2 (TLV75733) lost its thermal vias** | The board copy of `WSON-6-1EP…_ThermalVias` has 10 pads / 0 thru-hole; the library copy has 12 with 2 via pads (this is what the two DRC `lib_footprint_mismatch` hits on WSON-6 are). U6's copy kept its 2 vias; U2's has none, so its EP reaches GND only through the F.Cu pour. Last review's H1 (Tj ≈ 144 °C worst case at RθJA 100.2 °C/W) assumed a JEDEC board *with* via stitching — the real θJA is now worse than the H1 math. **Fix: re-sync the footprint from the library or add 2–4 × 0.3 mm vias EP → In1 GND.** Raw-file verified (pad counts), datasheet context from 2026-08-11 review. |
| WARNING | **W2. U7 (IS31FL3730) QFN-24 EP has 0 thermal vias** | Analyzer TV-001 (0/5 minimum). EP is on GND but connects only via F.Cu. U7 sinks the scanned display current (~320 mA at power-on defaults). **Fix: add 4–5 × 0.3 mm vias in the 2.5 × 2.5 mm EP.** Analyzer-derived, EP net raw-file verified. |

Hand-reflow note for W1/W2: open 0.3 mm vias in an EP wick some paste during reflow — expected and acceptable at this size. Apply slightly extra paste on the EP, and treat solder appearing in the via barrels as a useful visual confirmation the EP actually wetted (hard to inspect otherwise). Tenting them from the back keeps solder bumps off B.Cu; don't bother filling/plugging.

## Previous Review Delta (vs design_review_2026-08-11.md)

| Status | Count | Items |
|---|---|---|
| Fixed, now confirmed in copper | 6 | B1 D20/D21 orientation; M4 C20; M5 R39; M6 RL3/RL4 = 470 Ω; M7 C19; M9 R40 + 3V3_PROBES |
| Still open | 2 | Test points 0/98 nets (TE-001 — UART pads were recommended given the USB-reset debug trap); U2 thermal margin H1 (now aggravated → W1) |
| New (this review) | 5 | B1 gerber contamination; W1/W2 thermal vias; REF** annotation; silkscreen trio |
| Accepted/bench items unchanged | — | M1/M2 (SMF33A + D7 sizing documented), M3 (5 V budget bench check), M8 (AUX ripple firmware debounce), H1 bench measurement |

Pad-net checks this pass: **D20 = K→PUMP_PWM_OUT / A→GND, D21 = K→PUMP_FB_IN / A→GND** — last review's blocker is closed at the copper level (raw-file verified).

Schematic re-run shows no regressions: remaining error/warnings are the already-triaged false positives (PS-001 "circular enable" on U6, VD-003 R11 power math) plus PWR_FLAG/single-pin hygiene. MPN coverage still 100 %, `pcb/datasheets/` still synced (~30 PDFs).

## Mains Isolation (verified three ways)

The most safety-critical aspect of this board, and it holds up:

1. **Netclass coverage is complete.** Every net touching the mains section is in HV (`MAINS_L`, `MAINS_L_F`, `MAINS_N`, `PE`, `VALVE_OPEN`, `VALVE_CLOSE`) or HV_LOCAL (`Q1_G`, `Q2_G`, `RS1_m`, `RS2_m`, `U3_o6`, `U4_o6`, triac NC pads) — checked by enumerating pad nets of F2, RV1, C18, CS1/CS2, J2/J3, Q1/Q2, U3/U4, U1 against the `.kicad_pro` patterns. No orphan mains net escapes the rules.
2. **The `.kicad_dru` enforces reinforced spacing.** `hv_lv_isolation` requires 6.4 mm HV↔LV clearance (last rule = highest precedence), with documented rationale: MOC3063 body = 7.47 mm, placement = 8.78 mm. IEC 60664-1 at 250 Vrms / OVC II / PD2 asks ~5.0 mm reinforced creepage — 6.4 mm copper spacing exceeds it. Sub-rules cover N↔HV 2.0 mm, across-the-fuse 2.0 mm (F2 gap 4.5 mm), and valve-to-valve 2.0 mm.
3. **DRC + raw-file confirm.** kicad-cli DRC with these rules: **0 clearance violations** (16 warnings, all library-sync/silk). Point-in-polygon sampling of the In1 GND fill: **0/117 sample points in the mains band** (85–150, 28–48) vs 92 % coverage in logic regions — the isolation void is real, not a bounding-box illusion.

The only mains↔logic crossings remain the certified parts (MOC3063, HCPL-354, CPC1035N, IRM-03, C18/CS1/CS2 Y-caps), matching the schematic review's isolation inventory.

## PCB Verification (analyzer vs raw file)

- **Footprint count:** 124 in analyzer = 124 in raw file. Schematic↔PCB: only PCB-side extras are the two unannotated art footprints (`REF**` 8 mm logo + `REF**` QR at (109–118, 74.7)); no schematic component is missing from the board (cross_analysis XV-001 undercounts this as 1 because both share the ref `REF**`).
- **Board outline:** 94.5 × 99.75 mm from Edge.Cuts, matches gerber extents.
- **Pad-net spot checks:** U1 (mains pins 1/3, GND 14, PSU_5V 16), U2/U6 (WSON pinout incl. EP=GND), U7 EP=GND, D20/D21 as above — all consistent with the datasheet-verified schematic pass of 2026-08-11.
- **Zone fills are current:** all 14 zones `is_filled`, plausible ratios; gerbers exported the same minute as the board save.

## USB (J13 → U10 → U5)

- **Flow-through routing verified at copper level:** USB_D− islands are {J13.A7/B7, U10.3} + {U10.4, U5.13} — signal enters one USBLC6 pad, exits the other, exactly ST's intended flow-through. D+ equivalent per KiCad's own connectivity. The two DRC `unconnected_items` exclusions cover the USBLC6-2's internal pin 1↔6 / 3↔4 bonds — legitimate exclusions, already datasheet-verified 2026-08-11. (The plugin's island math splits D+ into 3 islands — arc-handling gap, disproven by DRC.)
- **Diff pair delta 0.46 mm** (D+ 26.05 mm / D− 25.59 mm) — far inside full-speed USB tolerance. D+ takes 2 vias, D− none; irrelevant at 12 Mb/s. No impedance control needed for FS.
- **ESD path:** C19 1 µF is 2.92 mm from U10 (esd_bypass ≤ 3 mm ✓), nearest GND via 2.0 mm from U10 — EMC ES-002 "no ground via near U10" is a false positive at any reasonable threshold.

## Power & Ground

- **Planes:** In1 solid GND under all logic (92 % sampled coverage incl. display corridor); In2 3V3 at 86 % fill; 464 GND stitching vias.
- **Trace widths:** mains 2.0 mm (HV class floor 1.2 mm) — huge margin at < 100 mA valve/PSU currents; PSU_5V 0.8 mm; 3V3_PROBES uniformly 0.8 mm (the M9 fix routed generously); 24 V / 5 V / VBUS 0.3–0.8 mm with plane assist — all comfortable per IPC-2221 at this board's loads. Minimum 0.2 mm segments on 3V3/GND are short pad necks; bulk distribution is by plane.
- **Decoupling placement (all within 3 mm, same side):** U5←C7 @ 2.4 mm, U2←C5 @ 2.1 mm, U6←C9 @ 1.5 mm, U7←C14 @ 2.85 mm + C20, U10←C19 @ 2.9 mm. EMC DC-001/DC-002 complaints are false positives: U8/U9 are HCPL-354 optos with no VCC pin; U10 has C19; U1 is a self-contained AC/DC module feeding bulk caps downstream.
- **VBUS PS-002 "2 islands":** zone + trace topology, electrically continuous (DRC clean) — benign.

## Thermal

- analyze_thermal.py produced no junction estimates (no extraction cache) — the quantitative reference remains H1 in the 2026-08-11 review. Layout reality check this pass: **U2 0 EP vias (W1), U7 0 EP vias (W2), U6 2 vias (adequate for ~0.1–0.2 W boost losses)**. U2 is the one to fix before the H1 bench check, otherwise the bench numbers will be measured against a worse-than-modeled board.
- Tombstoning: 32 × 0402 flagged for pad thermal asymmetry (info) — moot: hand reflow heats gradually and misbehaving parts get nudged on the spot.

## EMC (pre-compliance; risk score 11.5 before triage)

- **GP-001 (21 findings, 16 of them "0 % plane coverage" errors on DISP_R1-8/C1-8): FALSE POSITIVE.** Raw-file point-in-polygon sampling shows the In1 GND plane covers the U7→DS1 display corridor at 92 % — same as under the ESP32. The EMC tool mis-reads the multi-layer zone's per-layer fills. The remaining GP-001s (U3_A/U4_A 67–80 %, PUMP_* 70–78 %, 24V 87.5 %) are edges of the deliberate mains void / board-edge connector approaches — expected geometry, accept.
- **RP-001** missing stitching vias at DISP_R1-3 F↔B transitions (reference swaps GND↔3V3 plane): real but low-risk at display-scan speeds. Optional: a GND via + 3V3–GND cap near the display corridor transitions.
- **IO-001 "no EMC filtering" on J2/J3/J8-J12/J14/J15:** every port already carries deliberate protection (mains: MOV + snubbers; probes: R40 + PEC3205CS series-R/TVS — shunt caps would break 1-Wire; pump: 100 Ω + SMF33A; AUX: SMF51CA). The analyzer wants L/C structures it can pattern-match. Residual truth: long probe/pump cables are the radiated-emissions antennas — if pre-compliance fails 30–230 MHz, the fix is CM chokes at J8–J12/J14, not board changes. Keep as a contingency, not a change.
- **SW-001** U6 boost harmonics in 30–88 MHz: inherent to TPS61040; the hot loop is tight (C9 1.5 mm from U6, 2 EP vias). Note for the pre-compliance scan.
- **DC-003** C14/C15 far from via — minor, absorbed by W2's via work if done nearby.

## Manufacturing / DFM

- **DFM tier:** analyzer says "advanced" solely for annular ring — but only **2 of 585 vias** are 0.5/0.3 mm (0.1 mm ring; they're U6's footprint-embedded thermal vias). The population is 526 × 0.6/0.3 and 57 × 0.8/0.4. Common standard-tier fab capability covers 0.5/0.3; verify against your fab's standard capability rather than re-designing. Min track 0.2 mm, min drill 0.3 mm — standard everywhere.
- **FD-001 no fiducials** (error-rated): dismissed — owner confirmed hand placement under microscope; fiducials serve pick-and-place vision only.
- **TE-001 test points 0/98:** still open from last review; the UART TX/RX/GND pads remain the cheapest insurance given that USB attach resets the board and masks faults.
- **Gerbers:** all 11 layers + PTH/NPTH present, drill classification clean (585 vias, 93 component holes), alignment fails **only** because of B1's off-board logo. GR-004 paste/copper ratio 32 % is the THT + art copper skew — benign.
- **Silkscreen trio (cosmetic):** '24AC SENSE' text overlaps SW3's outline; U1 outline clipped by a mask polygon; Q4 footprint text self-overlap.
- **REF\*\* art footprints:** give the 8 mm logo and QR real references (G2/G3) so BOM/DRC tooling stops tripping on `REF**`, and confirm their ref texts are hidden.
- **Ordering:** 4-layer, 1.6 mm, copper finish not set in board setup (choose at order time). For hand reflow: **ENIG recommended** — flat pads matter for seating the QFN-24 0.5 mm and WSON parts under the microscope (HASL domes make them swim); **order the stencil** — syringe-pasting a 0.5 mm-pitch QFN and two WSON EPs is the hard way, a frameless stencil is a few euros with the board order.

## Component Lifecycle

Audit ran (45 MPNs) but every distributor returned "unknown" — same as 2026-08-11; the credentials/API path still doesn't produce lifecycle data. No EOL/NRND information available. Review gap, unchanged.

## False Positives / Reviewer Overrides (this pass)

| Claim | Reality |
|---|---|
| EMC GP-001: 16 display nets "0 % plane coverage" | In1 GND solid under display corridor (92 % sampled) — tool mis-parses multi-layer zone fills |
| EMC DC-002: no decoupling near U8/U10/U1 | U8/U9 are optos without VCC; U10 has C19 @ 2.9 mm; U1 is an AC/DC module |
| EMC ES-002: no GND via near U10 | GND via 2.0 mm away |
| DRC unconnected: U10 pads 1↔6, 3↔4 | USBLC6-2 internal bonds; flow-through routing verified; exclusions correct |
| PCB PM-002 error: G1 55 mm overhang | Not a placement error but a parked footprint → escalated to blocker B1 (gerber contamination) |
| PM-002 info: U5 −1.95 mm overhang | ESP32-C6 antenna correctly hangs off the board edge |
| DFM-001/002: annular ring below Class 2 | Affects exactly 2 embedded thermal vias; fab-capability check, not a redesign |
| Sch PS-001/VD-003 | Same false positives triaged 2026-08-11 |

## Positive Findings

1. Reinforced mains isolation enforced by rule, not hope: complete HV netclass coverage + 6.4 mm `.kicad_dru` constraint + clean DRC + verified plane void. The rule file's comments (pad-gap floors, MOC body limit) show the constraints were engineered, not defaulted.
2. All six schematic-review fixes confirmed in copper, including the D20/D21 blocker.
3. 100 % routing completion, zero DRC electrical violations, schematic↔PCB sync clean.
4. Tight decoupling discipline — every active IC's closest cap ≤ 3 mm, same side.
5. Solid In1 GND with 464 stitching vias; dedicated 3V3 plane; USB flow-through done right; antenna correctly overhanging the edge.
6. Sensible width hierarchy per netclass (2.0 mm mains, 1.2 mm HV floor, 0.8 mm probe power).

## Not Performed / Review Limits

- **SPICE:** no simulator installed (`brew install ngspice` would enable it) — unchanged from last review.
- **Thermal analyzer:** no quantitative Tj output (no datasheet extraction cache); relied on 2026-08-11 manual H1 analysis + this pass's via audit.
- **Lifecycle:** all 45 MPNs "unknown" — no usable EOL data.
- **Deep-review gate:** layout findings kept in report format; per-IC datasheet pass not regenerated (schematic unchanged since the verified 2026-08-11 pass).
- **Impedance control:** not analyzed beyond noting FS USB doesn't need it.
- **Creepage via slots/coatings:** review measured copper spacing in 2D; no slot/coating analysis (none appear intended).

## Fixes applied 2026-08-12 (same day, verified 19:36–19:43)

- **B1 FIXED:** off-board G1 (stale 10 mm logo) deleted; on-board art annotated G1 (8 mm logo) + G2 (QR), `REF**` gone. Gerbers + drills re-exported 19:43 (`kicad-cli --board-plot-params`); analyzer confirms alignment clean, F.Cu extents 93.7 × 98.85 mm inside the 94.5 × 99.75 mm outline.
- **W1 FIXED:** 2 × 0.5/0.3 mm free vias in U2's EP (matches the library's 2-via layout).
- **W2 FIXED:** 4 × 0.5/0.3 mm free vias in U7's EP. Drill count 585 → 591 confirms exactly the 6 new vias.
- DRC re-run: 0 electrical violations, warnings 16 → 14 (G1 library noise gone; remaining = WSON/terminal-block lib-sync + the cosmetic silk trio, all accepted).
- **Deliberately not changed:** silk trio, test points, fiducials (hand assembly), stitching vias at DISP transitions.

## Recommended Action Order

1. **B1:** delete or place G1, refill zones, re-export gerbers, confirm gerber extents = 94.5 × 99.75 mm.
2. **W1/W2:** restore U2's 2 thermal vias (library re-sync fixes the DRC mismatch too) and add 4–5 vias under U7's EP.
3. Add UART test pads (TE-001, carried over) while touching the board.
4. Hygiene: annotate the two `REF**` art footprints, silk trio, optionally 2 stitching vias at the DISP_R1-3 transitions.
5. Unchanged bench checklist from 2026-08-11: U2 thermals under OTA+display (after W1), 5 V peak draw, AUX opto margins, DET ripple.

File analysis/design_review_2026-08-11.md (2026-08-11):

# ValveController Schematic Review — 2026-08-11

**Project:** pcb/ValveController.kicad_sch (KiCad 9, single sheet) — 117 components, 101 nets, 50 unique parts, 100% MPN coverage
**Scope:** Schematic only (layout excluded at owner's request; PCB is mid-rework — 45 nets unrouted, new parts unplaced). Firmware excluded (adaptation to this board is planned separately).
**Analyzers run:** analyze_schematic.py (run 2026-08-11_1029), analyze_pcb.py --full (context only), cross_analysis.py, analyze_emc.py (out of scope, provisional), analyze_thermal.py (skipped itself — no extraction cache), lifecycle_audit.py (LCSC-only), kicad-cli sch erc, datasheet sync (~30 PDFs in pcb/datasheets/).
**Not run:** SPICE (no simulator installed), gerber analysis (no fab outputs), deep_review_gate.py (findings kept in reviewer format; citations spot-verified manually).
**Deep review:** four datasheet-driven subsystem reviews (power/pump, MCU/USB, AC-I/O, display) — full findings with citations in `analysis/deep_review_{power,mcu,acio,display}.json`.

## Overview

230 VAC-fed controller for an ESBE ARA661 230 V 3-point valve: fused mains (F2 500 mA time-lag) + S10K275 MOV → IRM-03-5 (5 V/600 mA) → TLV75733 3V3 (ESP32-C6-WROOM-1, IS31FL3730 + KWM-20881AGB 8×8 display) and TPS61040 boost → 24.3 V for the Wilo Para iPWM2 pump interface (CSD17313Q2 open-drain + 2.2k pull-up, J14). Two Z0103MN triac valve channels via MOC3063 zero-cross optos (J2), two CPC1035N PhotoMOS AUX pairs with HCPL-354 loop detection and SW3-switched 24 V wetting (J15), five DS18B20 1-Wire probe connectors (J8–J12), USB-C debug port (USB4145 + USBLC6-2).

## Verdict

**One blocker — two diodes mounted backwards (trivial fix). Everything else is in genuinely good shape.** All five custom/critical symbol pinouts (ESP32-C6 module, TPS61040, TLV75733, IS31FL3730, KWM-20881 matrix, plus USB4145/USBLC6/Z0103/MOC3063/CPC1035/HCPL-354) were verified pin-by-pin against manufacturer datasheets with zero mismatches. Fix the blocker, sweep the hygiene list, and the schematic is ready for the layout to catch up.

## Blocker

**B1. D20/D21 (SMF33A) are reversed on the pump interface — interface dead as drawn.**
Cathode (pin 1) to GND, anode (pin 2) to PUMP_PWM_OUT / PUMP_FB_IN. SMF33A is *unidirectional* ("color band denotes cathode" — Littelfuse SMF datasheet); as wired, the 24 V pull-up (R14 2.2k) forward-biases D20 permanently: pump PWM line clamped at ~0.7 V, ~10.3 mA wasted, R14 at ~233 mW (~93% of rating); D21 likewise clamps the 3V3-pulled feedback line so IO23 never reads high. Verified three independent ways: net topology, raw .kicad_sch pin-rotation geometry (D20 @ (355.0, 266.0) rot 90°, D21 @ (355.0, 280.0)), and PCB pad nets. **Fix: rotate both 180° (cathode to line, anode to GND).** Note the sibling parts are fine: D18/D19 are SMF51**CA** (bidirectional) and D8–D12 PEC3205**C**S are bidirectional (internal-circuit diagram, datasheet p.1) — orientation moot for those.

## High

**H1. TLV75733 (U2) thermal ceiling in a display+radio worst case** *(needs bench check)*.
WSON-6 RθJA 100.2 °C/W; full-on display at the IS31FL3730's power-on default 40 mA (~320 mA scanned) + 802.11b TX 382 mA ⇒ 1.19 W ⇒ Tj ≈ 144 °C > 125 °C at 25 °C ambient. Zigbee duty is far lower, so this is an OTA-over-WiFi + full-display corner. Mitigations: set the display current register low at init (firmware plan), and bench-measure U2 under worst case. (The analyzer's power budget misses U7 entirely.)

## Medium

- **M1. SMF33A clamp exceeds Q5/U6 30 V abs-max — accepted, part choice CONFIRMED correct.** VBR 36.7–40.6 V, VC up to 53 V: a hard transient can exceed CSD17313Q2/TPS61040 ratings before clamping. However the Wilo iPWM guide (fig. 11 spec table) allows the feedback line up to **UoH = 32 V in abnormal boiler operation**, so a standoff below 33 V would conduct in-spec — SMF33A is the right part; do NOT downsize. Residual fast-transient exposure is mitigated by the 100 Ω series resistors (R15/R17) and D7's 27 V zener on the rail; accept and document.
- **M2. D7 (BZT52B27, 500 mW) overdissipates in a sustained FB-open fault** — boost at current limit into the clamp ≈ 0.7–0.8 W. Fault energy is bounded (boost ILIM), but the clamp is sacrificial, not continuous. Accept (document) or upsize (SMBJ-class / SOD-123F 1 W+).
- **M3. 5 V budget tight** — worst case ≈ 530 mA of IRM-03-5's 600 mA (WiFi TX 382 + display ~80 + boost ~67). Hiccup-mode OCP means sustained overload = restart loop. Bench-measure real peaks; 121 µF of 3V3 bulk rides ms-scale bursts.
- **M4. U7 C_FILT (pin 5) hard-grounded** — datasheet calls the cap "required" (0.1 µF, Fig. 1); likely benign with audio disabled (A_EN=0, IN grounded) but unqualified. Add 0.1 µF or bench-verify.
- **M5. GPIO15 (JTAG-select strap) floating** — datasheet §4.4 explicitly forbids high-Z on this strap. Inert today (eFuse default ignores it); add a pull for insurance.
- **M6. AUX LED drive margin thin** (found independently by two reviewers) — 680 Ω gives 1.82 mA at the worst corner vs CPC1035N's 2 mA guaranteed turn-on, and Clare recommends 10 mA above 60 °C. Change RL3/RL4 to 470–560 Ω.
- **M7. No local VBUS bypass at J13/U10** (analyzer UC-001 confirmed) — nearest caps sit behind D5; ST's USBLC6 app note wants a local bypass for clamp effectiveness. Add 1–4.7 µF at U10.5/J13. Debug-only port softens urgency.
- **M8. AUX detect ripple in external-24VAC mode** — 100 Hz pulsing vs 15.9 Hz RC corner: IO20/21 see ripple, not DC. Firmware must integrate/debounce (DC-wetting mode via SW3 is clean).
- **M9. 3V3 pin on J8–J12 is unprotected** — probe power pin has no series element or clamp (data pin has both); one field-wiring short resets the whole controller. Add per-connector (or shared) series R / polyfuse on the probe 3V3 feed.

## Low / hygiene

- U7 SDB hard to 3V3 — a wedged display driver can only be reset by power-cycling 3V3; a pull-up + GPIO would restore the datasheet's SDB reset feature. (Optional.)
- C1 100 µF/6.3 V on 3V3 = 52% of rating — just over the 50% X7R guideline; fine functionally (C5/C6/C15 in parallel).
- SW3 contact spec 24 VDC vs 24.3 V rail (+1.3%) — negligible, noted for completeness.
- HCPL-354 wetting current 0.64 mA below the 1 mA characterized CTR point — ~4× margin on the computed floor; scope at temperature extremes.
- SW3-ON + external device combination can leak ≤ ~1.6 mA into external sense inputs — installation/manual note, not a defect.
- J2/J3 "250 V" property vs 253 V (230 V+10%) — confirm Phoenix's working-voltage definition (SPT 2,5 family is standard 230 V kit; almost certainly fine).
- NC-flag cleanup: add flags on IO11 + RXD0; delete stale flags sitting on connected pins IO4, IO5, RS8.2.
- U5 symbol types its 10 GND pins as power-out → 11 spurious ERC errors; retype power_in/passive.
- Delete the 0.0127 mm dangling wire stub at (349.25, 97.79) [schematic units mm×0.01 per ERC: @(3.4925, 0.9779)].
- 16 off-grid endpoints in the J8–J12 / D18–D21 / U10 region — grid-snap sweep.
- D20/D21 use Device:D_Zener; switch to Device:D_TVS when rotating (fixes the analyzer's "J14 unprotected" false negative too).
- Missing PWR_FLAGs on 24V_FB/24V_SW/VBUS (analyzer RS-001) — ERC hygiene only.
- No test points anywhere; given that USB attach resets the board and masks faults (documented debug history), add UART0 TX/RX/GND pads or a 3-pin header — TXD0/RXD0 are free.

## Info / design questions

- **R13 pulls Q5's gate UP to 3V3 — RESOLVED: deliberate and correct.** Pump line actively held low whenever the MCU isn't driving (boot, reset, crash). Per the Wilo iPWM Technical Guide V1.0 (now in pcb/datasheets/) iPWM2 profile: <7 % duty = stop, wire-break = STOP — so line-low = 0 % = STOP. The 2026-08-05 interface spec documents exactly this rationale ("reset/crash/unpowered = pump stopped"). Opposite polarity from the other outputs' pulldowns is intentional safe-state logic, not an error.
- CC1/CC2 have no dedicated ESD device — acceptable for an internal debug port.
- Display power-on defaults are safe: 40 mA scanned ≈ 1/8 duty vs 100 mA/1-10-duty matrix peak rating (~2.5× margin); explicit CS-register init still recommended.
- Display pixel remap for the firmware plan (driver→matrix): R1→ROW2, R2→ROW4, R3→ROW1, R4→ROW3, R5→ROW6, R6→ROW8, R7→ROW7, R8→ROW5; C1→COL4, C2→COL6, C3→COL1, C4→COL7, C5→COL8, C6→COL2, C7→COL3, C8→COL5.

## Verified correct (datasheet-cited highlights)

- **ESP32-C6 module:** all 29 pins verified against Espressif Table 3-1 — no numbering errors; EN RC = Espressif's exact recommended 10k/1µF (~278× margin on tSTBL); BOOT strap textbook, C8 settles 1 ms before the 3 ms sampling window; IO8 strap pulled up, sole load; USB D+/D- polarity correct (IO13=D+/IO12=D-); no auto-reset circuit needed with native USB-JTAG — correct.
- **USB:** USB4145 pin map exact; USBLC6-2 channels correct (D+ on 1&6, D- on 3&4, flow-through); CC pulldowns 5.1k one-per-pin; SBU correctly NC.
- **Boost:** TPS61040 pinout exact; Vout = 1.233 × (1+249/13.3) ≈ 24.31 V; R10/R11 in TI's recommended ranges; C13 feedforward correctly across R10; L1 is literally TI's recommended inductor (Isat 2.9× ILIM); D6 60 V/1 A ample; C9/C10/C11 meet TI minimums.
- **LDO:** TLV75733 pinout exact; EN-to-IN is TI's documented always-on practice; output capacitance ≫ stability minimum.
- **Mains front-end:** F2 = 500 mA time-lag NANO2 (tolerates IRM-03 20 A inrush, ~12× line-current margin); S10K275 correct for 230 VAC; C18/CS1/CS2 genuinely X1/Y2-certified; D4/D5 OR-ing verified by pin names, no backfeed.
- **Triac channels:** Z0103MN pinout verified (onsemi second source); MOC3063 app-note topology exact; LED drive 6.9–11.1 mA vs 5 mA IFT; gate current 3–11× IGT, fault-bounded under MOC ITSM; snubbers correctly across each triac; boot-safe pulldowns everywhere.
- **AUX/detect:** CPC1035N pinout exact; SMF51CA correctly bidirectional across floating pairs; HCPL-354 orientation correct (E→GND, C→DET); detection logic traced end-to-end (HIGH=closed by current diversion — see deep_review_acio.json explainer).
- **1-Wire probes:** all five channels identical and correctly mapped (J8→IO0, J9→IO1, J10→IO10, J11→IO5, J12→IO4); 4.7k pull-ups per DS18B20 convention; PEC3205CS 5 V standoff / ≤20 pF / bidirectional — correct choice; powered (non-parasite) mode.
- **Display:** IS31FL3730 all 25 pins exact; matrix symbol 16/16 against Luckylight series pinout; row-anode ↔ source-side polarity correct; I2C 0x60, no conflicts; C14+C15 decoupling per datasheet Fig. 1.
- **Isolation inventory for the layout stage:** MOC3063 5 kVrms, HCPL-354 3.75 kVrms, CPC1035N 1.5 kVrms, IRM-03 transformer — the only mains↔logic crossings; netlist shows no accidental galvanic path.

## Analyzer false positives (triaged, with corrected math)

| Analyzer claim | Reality |
|---|---|
| PS-001 error: circular enable U6→U6 | EN tied to 5 V (=VIN), not its own output |
| U6 Vout = 11.83 V | Heuristic used 0.6 V Vref; real VFB 1.233 V → 24.3 V |
| VD-003: R11 at 43 mW | Only VFB across R11 → 0.11 mW (380× lower) |
| PS-001: U2 PG unknown | TLV75733P has no PG pin in any package |
| U2/U6 "missing capacitors" / "missing decoupling on FB/SW" | All required caps present; FB/SW pins don't take decoupling |
| EP-AUD: J15/J2/J3/J14 "no ESD" | J15 has SMF51CA differential pairs; J2/J3 have MOV+snubbers (correct class for mains); J14 has D20/D21 (reversed, and invisible to the detector due to D_Zener lib_id) |
| MU-1: TEMP_SOURCE on non-ADC GPIO10 | Probes are DS18B20 1-Wire (title block); no ADC involved |
| AC-2: no filter caps on temp inputs | Correct for 1-Wire — caps would hurt the bus |
| NT-001 H3/H4; RS-001 rails; DS-002 | Logo/hole symbols; missing PWR_FLAGs only; resolved by datasheet sync |
| kicad-cli: 85 lib warnings, 11 U5 pin_to_pin errors | Environment noise + symbol pin-type hygiene (see Low list) |

## Not performed / review limits

- **SPICE:** no simulator installed (`brew install ngspice` would enable boost/filter verification).
- **Thermal analyzer:** skipped itself (no extraction cache); H1 covers the dominant risk manually.
- **Lifecycle:** LCSC-only audit returns "unknown" for all 45 MPNs; needs DigiKey/Mouser keys for real EOL status.
- **Layout / EMC / cross-domain:** excluded per owner request; re-run after routing completes (current EMC output reflects the unfinished layout).
- **Deep-review gate script:** not run (reviewer-format JSONs); key citations spot-verified by the orchestrator instead (D20/D21 three ways, PEC3205CS directionality, 1-Wire reclassification, R13 pull-up).
- **KWM-20881AGB exact datasheet** unpublished — AVA sibling used as pinout proxy (16/16 match; AGB current ratings may differ slightly).
- **Wilo Para iPWM2 guide** was absent during the agent pass (R13/R14 checks initially rested on the approved board spec); the guide has since been fetched to `pcb/datasheets/Wilo_iPWM_Technical_Guide_V1.0_pump_J14_interface.pdf` and closes the R13 polarity question (see Info section). R14=2.2k is Wilo's recommended pull-up (valid 1–2.5 k).

## Fixes applied 2026-08-11 (same day, scripted with netlist-diff gate)

Backup: `pcb/ValveController.kicad_sch.pre-review-fixes.bak`. Netlist diff verified to contain exactly the intended changes; ERC errors 17→4 (only the H3/H4 logo-pin noise remains); analyzer re-run confirms all changes. **Not committed to git. If the project is open in KiCad, use File → Revert before continuing work.** The PCB now needs F8 (Update from Schematic): place C19 (at U10/J13), C20 (at U7), R39, R40 + the D20/D21 pad-net swap.

- **B1 FIXED**: D20/D21 rotated 180° — cathodes now on PUMP_PWM_OUT/PUMP_FB_IN, anodes on GND.
- **M4 FIXED**: U7 pin 5 lifted from GND; C20 100 nF (GRM155R71C104KA88D) added on new net C_FILT.
- **M5 FIXED**: NC flag removed from IO15; R39 10 k pull-up to 3V3 added (strapped high like the old board).
- **M6 FIXED**: RL3/RL4 680 → 470 Ω (RC0402FR-07470RL); worst-corner LED current now 2.64 mA vs 2 mA spec.
- **M7 FIXED**: C19 1 µF (CL05A105KP5NNNC) added directly on VBUS at U10/J13.
- **M9 FIXED**: J8–J12 pin 3 moved to new net 3V3_PROBES behind R40 100 Ω 1206 (ERJ-P08J101V) — a field short now draws ~33 mA instead of dropping the rail. (The schematic analyzer's new RS-001 info on 3V3_PROBES is the expected consequence; native ERC is clean.)
- **Hygiene FIXED**: NC flags added on IO11 + RXD0 (correct pin-12 position re-derived — the review's original coordinate was pin 11); stale NC flags on IO4/IO5 deleted; U5 symbol GND pins retyped power-out → passive (11 ERC errors gone); 1.27 mm dangling wire stub at H4 deleted.
- **Deliberately not changed**: SMF33A stays (Wilo UoH 32 V), D_Zener glyph stays, D7 stays (documented sacrificial), PWR_FLAGs not added, off-grid endpoints left for the GUI, SDB rework not done, H3/H4 logo-pin ERC noise left.
- Follow-up in progress: DigiKey URL properties for the new/changed parts (RL3/RL4's old 680R product link was stale).

## Recommended action order

1. Rotate D20 + D21 (blocker). Keep SMF33A (33 V standoff required by Wilo UoH=32 V abnormal — M1) and keep the polarized D_Zener glyph (semantically correct for a unidirectional TVS; the analyzer's EP-AUD J14 false-negative is an analyzer limitation, not worth a misleading bidirectional symbol).
2. RL3/RL4 680 → 470–560 Ω (M6). Add 1 µF at VBUS/U10 (M7). Add 0.1 µF on C_FILT or bench-clear it (M4). Pull on GPIO15 (M5). Series R/polyfuse on probe-connector 3V3 (M9).
3. Hygiene sweep: NC flags, stale NC removals, U5 GND pin types, PWR_FLAGs, wire stub, off-grid endpoints, UART test pads.
4. Bench checklist for first prototype: U2 thermals under OTA+display (H1), 5 V peak draw (M3), AUX opto margins at temperature (M6/AC-5), DET ripple behavior for firmware debounce design (M8).
5. Decide on D7 sizing or document it as sacrificial (M2).

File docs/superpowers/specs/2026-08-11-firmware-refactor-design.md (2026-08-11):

# Firmware refactor — deduplicate diagnostics, unify config, split zigbee.c

Status: approved 2026-08-11. Two releases: **1.7.0** (refactor, behaviour-preserving) then **1.7.1** (sdkconfig only).

## Motivation

Three goals were named: room for the display/AUX board, maintainability, flash headroom.

**Flash headroom is already satisfied and is not a design driver.** Measured on the 1.6.4 build:

| | bytes | share |
|---|---|---|
| Binary total | 712,864 | 37.5% of OTA slot |
| OTA slot (`ota_0`/`ota_1`, 0x1D0000 each) | 1,900,544 | 1,159.8 KiB free |
| Zigbee stack (`zboss_stack` + `zb_api` + `zboss_port`) | 354,147 | 49.7% of image |
| `libmain.a` — all of `main/` | 23,118 | 3.2% |
| `libconsole.a` (esp_console + argtable3) | 15,734 | 2.2% |
| `libctrl_core.a` | 5,986 | 0.8% |

Half the image is the Zigbee stack; project code is 3%. No refactor of `main/` can move the image size
meaningfully — a perfect rewrite of everything hand-written here saves less than the console library.
Size work is therefore isolated into 1.7.1 as a single sdkconfig change, and 1.7.0 is judged purely on
duplication removed and seams created.

The 1.6.1–1.6.4 debugging session left scar tissue: instrumentation was added three times in three
places under time pressure. That duplication sits exactly where the display/AUX firmware must land.

## Release 1.7.0 — refactor

### 1. Extract the RTC history mechanism

Three independent implementations of the same pattern (magic word + seq + live `cur` + `hist[4]`,
shift-on-boot, reset-reason label, bounded-`snprintf` formatter):

| file | struct | roll-on-boot | formatter |
|---|---|---|---|
| `main/taskhb.c` | 20-31 | `hb_boot_report` 65-90 | `hb_format` 92-118 |
| `main/sensors_hw.c` | 80-92 | inline in `sensors_start()` 226-256 | `fmt_run` 325-343 + `sensors_format_stats` 349-363 |
| `main/zigbee.c` | 642-667 | `zb_temp_stats_init` 771-800 | `fmt_run_block` 720-737 + `zigbee_format_temp_stats` 739-751 |

`esp_reset_reason_t → const char *` exists twice (`taskhb.c:35-49` `rr_name`, `zigbee.c:753-769`
`reset_reason_name`) and the two copies already disagree by two cases.

**Payloads stay typed per owner.** Heartbeat timestamps, 1-Wire tallies and attribute-write tallies are
different data; a generic `void *` ring holding all three would be worse than the three copies. Only the
mechanism is shared.

New portable module `components/ctrl_core/diag_ring.c` + `include/ctrl_core/diag_ring.h`. **Zero ESP
dependencies** — it is picked up automatically by the host suite's `../components/ctrl_core/*.c` glob.
`main/` retains ownership of the `RTC_NOINIT_ATTR` storage and of calling `esp_reset_reason()`, because
neither can cross into the portable core.

```c
#define DIAG_RING_DEPTH 4

typedef struct { uint32_t magic; uint32_t seq; } diag_hdr_t;

/* true  = storage survived the reset (seq bumped, caller should record the ended run)
   false = cold start (hdr zeroed, magic stamped, seq = 1) */
bool diag_ring_warm(diag_hdr_t *hdr, uint32_t magic);

/* hist[n] <- hist[n-1] for n descending; hist[0] is left untouched for the caller
   to overwrite with its own typed fields. */
void diag_ring_shift(void *hist, size_t elem, uint8_t depth);

const char *diag_reset_reason_name(int reason);   /* esp_reset_reason_t widened to int */

/* Bounded append. Returns the new used length. Never writes past n-1, always NUL-terminates. */
size_t diag_appendf(char *o, size_t n, size_t used, const char *fmt, ...);
```

`diag_appendf` replaces `fmt_run`, `fmt_run_block`, and the pattern `hb_format` inlines without
extracting. Each hand-rolls the same `u += k; if (u >= n)` bounds arithmetic — the single most
off-by-one-prone code in the tree, and currently untested. It gets tests.

**Host tests:** warm/cold transition and seq behaviour; shift correctness with sentinel-filled arrays
(including depth 1 and full-depth wrap); `diag_appendf` truncation at exact boundary, zero-length
buffer, and repeated append past capacity.

### 2. Collapse the config duplication

`main/config.c:228-269` (`config_apply_custom`, keyed on `ATTR_*`) and `ctrl_core/config_map.c`
(`tunable_apply`, keyed on `TUNABLE_*`) independently implement the same clamping switch over the same
fields with the same ranges: `heat_threshold` 10–60, `cool_threshold` 0–40, `kp` 0.5–15, `ki` 0–5,
`gov_high` 36–60, `gov_low` 0–16, `alarm_dwell` 10000–3600000, `deadtime_s` 0–120, `pi_deadband` 0–1,
`heat`/`cool_setpoint` 17–35.

Only the `ctrl_core` copy has tests. The untested copy is the one that actually serves Zigbee writes.
They will drift.

Defaults are duplicated the same way: `config.c:16-24` (`DEFAULTS`) and `config_map.c`
(`tunable_cfg_defaults`), same numbers as separate literals.

**Change:** delete `config_apply_custom`'s clamping body; replace with an `ATTR_* → TUNABLE_*` mapping
that delegates to `tunable_apply`. Derive `DEFAULTS` from `tunable_cfg_defaults` rather than restating
it. One definition of each clamp, one definition of each default, both tested.

**No NVS schema change** — the v1→v2→v3 blob migration is untouched.

**To verify during implementation:** `tunable_apply`'s value type must accommodate what the display/AUX
work will add. That feature introduces a per-channel boolean `input_mode`, not a clamped numeric. If the
existing signature is numeric-only, extend it in this pass rather than forcing the next feature to
reintroduce a second apply path — which would undo this whole item.

**Host test:** a Zigbee-side attribute write and the equivalent tunable write produce identical clamped
results across every mapped field, including out-of-range values at both ends.

### 3. Split `zigbee.c`

984 lines doing five jobs. Split along the seams already present:

| file | contents |
|---|---|
| `zigbee.c` | init, endpoint/cluster registration, join/steer signal handling |
| `zigbee_attrs.c` | custom cluster `0xFC00` dispatch (`attr_cb`, ~157 lines) + the `ATTR_*→TUNABLE_*` map from §2 |
| `zigbee_telem.c` | telemetry task, temperature reporting, the four `configure_reporting_*` |
| `zigbee_diag.c` | attribute-write tallies, rebuilt on `diag_ring` |

Statics shared across the split move to an internal `zigbee_internal.h`, not the public `zigbee.h`.

This is the split that pays: the display/AUX board adds two on/off switch endpoints, and its per-channel
`input_mode` config lands in the custom-cluster dispatch.

### 4. Thin `sensors_hw.c`

363 → ~250 lines. The ring moves to `diag_ring`; the roll-on-boot comes out of `sensors_start()`, where
it is currently interleaved with mutex creation and task startup (`226-256`). No change to the 1-Wire
driver, EMA filter, or fault classification.

### 5. Housekeeping

Delete the 26 untracked `firmware/test_host/build-*/` directories (304 MB; each carries its own fetched
Unity copy). Add `.gitignore` entries for `firmware/test_host/build*/` and `firmware/.cache/`.

### Seams for display/AUX — documented, not implemented

No new peripheral files are created in 1.7.0. The refactor leaves these attachment points, recorded here
so the next spec can rely on them:

- **Peripheral tasks** follow the existing `*_hw.c` pattern (`sensors_hw`, `valve_hw`, `ui`): own task,
  own heartbeat id. `display_hw.c` and `aux_hw.c` attach the same way.
- **`hb_id_t`** gains `HB_DISPLAY` / `HB_AUX` by adding enum entries. The heartbeat payload is
  `last_ms[HB_COUNT]`, so it widens automatically; `diag_ring` itself is payload-agnostic and needs no
  change.
- **Portable display logic** — page state machine, scroll/render, digit font — belongs in `ctrl_core`
  so the host suite can test it, as its spec requires. Only I2C transport lives in `main/display_hw.c`.
- **Endpoint registration** for the two on/off channels goes in the post-split `zigbee.c`; their command
  handling in `zigbee_attrs.c`.

### Verification

- Host suite green and grown: 17 binaries today, plus the `diag_ring` and unified-clamp tests. Full
  clean cycle is ~9 s, so it runs on every step.
- `idf.py size` diffed before/after. Expect roughly break-even; a large swing means something was
  dropped or duplicated by mistake.
- Flash over USB, then **soak on mains with USB unplugged past the 40 s mark** — the 1.6.4 fault only
  appears with no host attached, and attaching USB both resets the board and masks it.
- Confirm `fault_bitmap: 0`, temperatures flowing, and the plant regulating in Z2M.

## Release 1.7.1 — sdkconfig only

The build is currently `CONFIG_COMPILER_OPTIMIZATION_LEVEL_DEBUG=y` (`-Og`). Set
`CONFIG_COMPILER_OPTIMIZATION_SIZE=y`. Nothing else changes in this release, so any misbehaviour on the
plant is unambiguously attributable.

**Assertions stay enabled** (`CONFIG_COMPILER_OPTIMIZATION_ASSERTIONS_ENABLE=y`, level 2) and
`CONFIG_ESP_ERR_TO_NAME_LOOKUP` stays. Both are diagnostics on a device that was recently debugged
blind; trading them for bytes buys headroom already in surplus.

Expected saving is 10–20% of the image, unmeasured — no Release-vs-Debug baseline exists yet. Measure,
record in `firmware/README.md`, and keep the change only if the plant soaks clean.

Same verification as 1.7.0, plus `idf.py size` before/after recorded in the release notes.

## Out of scope, and why

- **No `constants.h`.** Timing and threshold `#define`s currently sit at the top of the file that uses
  them (`SWEEP_PERIOD_MS`, `CYCLE_MS`, `TICK_MS`, `EMA_TAU_S`, `SELF_HEAL_*`, `STEER_RETRY_*`,
  `TELEMETRY_PERIOD_MS`, DS18B20 command bytes). Centralising them creates a header the whole tree
  depends on and rebuilds on every tuning tweak. Scattered-but-local beats central-and-coupled here.
- **Test harness untouched.** 17 executables each relinking the whole of `ctrl_core` is wasteful in
  principle and costs 9 s in practice. Not worth the churn.
- **No cuts to console/argtable3, Green Power, or a switch to `ZB_ZED`.** These are the largest
  remaining size levers after the optimisation flip, and every one of them degrades observability or
  capability to buy space that is already free.
- **No NVS schema change.** The `input_mode` fields the display/AUX board needs will force a v4
  migration; that belongs in that feature's own release, not bundled here.

## Risk

Everything in 1.7.0 is mechanical movement rather than logic change, **except the config unification**,
which genuinely replaces two implementations with one — hence the dedicated equivalence test.

The exposure is that this touches the Zigbee path Z2M talks to, on a plant that only came back into
service on 2026-08-10. Mitigation is the soak in Verification, performed the hard way (no USB), because
this codebase has already demonstrated a fault that is invisible whenever it is observable.

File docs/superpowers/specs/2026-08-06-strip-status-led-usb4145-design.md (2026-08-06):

# Strip status LED · USB-C → USB4145 — Design Spec

**Date:** 2026-08-06
**Scope:** `pcb/ValveController.kicad_sch`, `pcb/ValveController.kicad_pcb`, `tools/`, docs. Firmware untouched.
**Context:** The 8×8 matrix (DS1 + U7 IS31FL3730, merged 2026-08-05) supersedes the single status LED. Separately, J13 moves to a connector that can actually be hand-soldered.

Both changes land while the PCB is unrouted (`HEAD` has 331 segments / 82 vias; working tree has 0), so neither costs a rip-up.

## 1. Status LED removal

D1 (0402 LED, IO15 active-low) is redundant now that the matrix can render state. **Both D1 and R4 go**, and IO15 is left unconnected.

### 1.1 Why R4 goes too

R4 had a second job: the firmware spec (2026-07-13, §8.1) noted it also held the GPIO15 JTAG-source strap high. Per **ESP32-C6 Series Datasheet v1.5**:

- **Table 3-1** — GPIO15 default configuration is **Floating**. Unlike GPIO9, it has no internal weak pull-up.
- **§3.4** — *"This pin does not have any internal pull resistors and the strapping value must be controlled by the external circuit that cannot be in a high impedance state."*
- **Table 3-7** — with the factory-default eFuses (`DIS_PAD_JTAG=0`, `DIS_USB_JTAG=0`, `JTAG_SEL_ENABLE=0`) GPIO15 is **Ignored** and the JTAG source is the USB Serial/JTAG controller.

§3.4's warning describes the case where the strap is *active*. Table 3-7's bolded default row governs this board: the strapping latch still samples GPIO15 at reset, but nothing reads the value. A floating pin there changes nothing.

Keeping a pull-up would insure exactly one scenario — burning `JTAG_SEL_ENABLE`, after which a floating GPIO15 could divert JTAG to the MTDI/MTCK/MTMS/MTDO pads and present as dead hardware. That is a deliberate, knowing act, not an accident.

Against that, GPIO15 is scarce: the display/AUX design left IO4, IO5, IO8, IO16 free, and IO4/IO5/IO8 are all strapping pins. GPIO15 and GPIO16 are the only clean non-strapping spares. A 10 k pull-up would not block reuse, but it would make the pin idle high — awkward for an open-drain bus, a chip select, or an active-high enable that must be off at boot. An unencumbered spare is worth more than insurance against an eFuse burn that is not planned.

**If `JTAG_SEL_ENABLE` is ever burned, GPIO15 must be pulled high externally.** Recorded in the firmware GPIO map.

### 1.2 IO15 disposition

No net. A `no_connect` flag on U5's IO15 pin at `(134.62, 71.12)`, matching the existing no-connect at `(134.62, 66.04)` in the same pin column. In the PCB the pad takes the board's standard unconnected name, `unconnected-(U5-IO15-Pad23)`.

### 1.3 Schematic edits

Delete the whole branch:

| Element | Location |
|---|---|
| Symbol `D1` | `(182.88, 256.54)`, uuid `0385bbdc…` |
| Symbol `R4` | `(182.88, 241.3)`, uuid `4c9767a4…` |
| Wire | `(182.88, 261.62)`–`(182.88, 266.7)` |
| Wire | `(182.88, 251.46)`–`(179.07, 251.46)` |
| Wire | `(182.88, 231.14)`–`(182.88, 236.22)` |
| Wire | `(182.88, 246.38)`–`(182.88, 248.92)` |
| Wire | `(179.07, 248.92)`–`(182.88, 248.92)` |
| Global label `LED_A` | `(182.88, 266.7)` and `(179.07, 248.92)` |
| Global label `STAT_LED` | `(179.07, 251.46)` |
| Global label `3V3` | `(182.88, 231.14)` |

Replace: the `STAT_LED` global label at `(134.62, 71.12)` sits directly on U5's IO15 pin with no stub wire → becomes `(no_connect (at 134.62 71.12))`.

Nets `STAT_LED` and `LED_A` cease to exist.

### 1.4 PCB edits

Delete the `D1` footprint (`LED_SMD:LED_0402_1005Metric`, ~`(91.8, 108.075)`) and the `R4` footprint (`Resistor_SMD:R_0402_1005Metric`, ~`(90.7, 108.075)`). Nothing on either was routed. U5 pad 23 takes `unconnected-(U5-IO15-Pad23)`.

### 1.5 Documentation

- `README.md:51` — drop "status LED (**active-low**)" from the I/O row.
- `firmware/README.md` — remove the Status LED row from the GPIO map; replace the "LED legend" subsection with gestures only.
- `firmware/BENCH_CHECKLIST.md:108` — step 1.5 becomes a USB-console liveness check instead of an LED watch.

### 1.6 Firmware deliberately unchanged

`ui.c` (`PIN_LED`, `led_task`, `blink`) and `app_main.c:17` (`PIN_STAT_LED`) stay. They will be replaced wholesale by the IS31FL3730 display work rather than churned twice.

Consequence until then: `led_task` drives IO15, which now goes nowhere — no LED, no resistor, no net. Inert. Strapping values are latched at Chip Reset and held until power-down (datasheet §3), so runtime toggling cannot affect JTAG selection even if `JTAG_SEL_ENABLE` were burned. Bring-up in the interim relies on the USB-Serial-JTAG console, which reports more than the LED did.

## 2. J13 → GCT USB4145-03-0170-C

### 2.1 Rationale

**Hand-solderability.** On the USB4115-03-C the shell wall stands in front of the contact row, so the pads cannot be reached with an iron. The USB4145 keeps all 16 contacts clear on the surface. This is a build-process decision, not a manufacturability rescue — both parts are vertical and architecturally identical (SMT contacts, 4 THT shell stakes, 2 NPTH pegs, no `Edge.Cuts`), so USB4115 was never a UJ20-style defect.

Secondary gains:

- **Exact pin match.** USB4145's footprint has 16 pads; the symbol in use, `Connector:USB_C_Receptacle_USB2.0_16P`, has 16 pins. KiCad's stock USB4115 footprint carries 24, leaving 8 dangling.
- **Correct stake length.** `0170` = 1.70 mm shell stake, right for a 1.6 mm board. `0070` and `0230` are the wrong-board-thickness variants.
- **Already proven** in `../Ikawa/board`, with a normalised footprint, a TraceParts STEP, and an import script.
- **In stock** — [DigiKey 16649098](https://www.digikey.com/en/products/detail/gct/USB4145-03-0170-C/16649098).

KiCad versions match (both `20260206` / 10.0), so no `kicad-cli fp upgrade` is required.

### 2.2 Licence handling

The footprint is SnapMagic-derived. Their terms permit designing, manufacturing and distributing *boards* built with the model, but prohibit redistributing the *model files*. Ikawa vendors it because that repo is closed source. **HydroMix is public and MIT**, so vendoring it here is exactly the prohibited case.

Therefore:

- Port Ikawa's `tools/import_usb4145.py` into `tools/`, self-contained (inline the ~90 lines of s-expression parse/dump it needs from `kisym`, rather than importing a module nothing else here uses). It drops the spurious `Edge.Cuts` obround around the right locating peg — an export artifact; GCT's drawing calls out a plain Ø0.71 hole, and the NPTH pads are authoritative — and renames stake pads `S1..S4` → `SH`.
- Outputs `pcb/Kleist2.pretty/USB_C_Receptacle_GCT_USB4145-03-0170-C_Vertical_SMT.kicad_mod` and `pcb/3dmodels/usb4145-03-0170-c.stp`, the latter referenced as `${KIPRJMOD}/3dmodels/…` per existing convention.
- **`.gitignore` both outputs**, with a comment naming the script and the reason. Anyone rebuilding runs it against their own SnapMagic download.

Fabrication outputs — Gerbers, drill, CPL, BOM — are board designs and are explicitly permitted, so a normal CM handoff is unaffected.

### 2.3 Schematic edits

`J13` keeps symbol `Connector:USB_C_Receptacle_USB2.0_16P`. Properties change only:

| Property | New value |
|---|---|
| Value / MPN | `USB4145-03-0170-C` |
| Footprint | `Kleist2:USB_C_Receptacle_GCT_USB4145-03-0170-C_Vertical_SMT` |
| Datasheet | `https://gct.co/files/drawings/usb4145.pdf` |
| DigiKey | `https://www.digikey.com/en/products/detail/gct/USB4145-03-0170-C/16649098` |

The existing Datasheet property points at `usb4105.pdf` while the part is a USB4115 — a pre-existing mismatch, corrected by this change.
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

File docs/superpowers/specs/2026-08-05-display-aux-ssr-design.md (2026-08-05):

# 8×8 LED matrix display + 2 aux 24 VAC SSR channels — design

**Date:** 2026-08-05
**Branch:** `feat/display-aux` (based on `main` @ 8eff6f9, includes pump iPWM leaf)
**Scope:** Schematic (`pcb/ValveController.kicad_sch`), firmware (display UI + 2 Zigbee switch endpoints), Z2M external converter. PCB placement/routing is a follow-up task.
**Goal:** Local glanceable status display (valve %, state, temps) paged by a button, plus two independently Zigbee-commanded isolated 24 VAC signal pass-through switches.

## Requirements (user-approved)
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

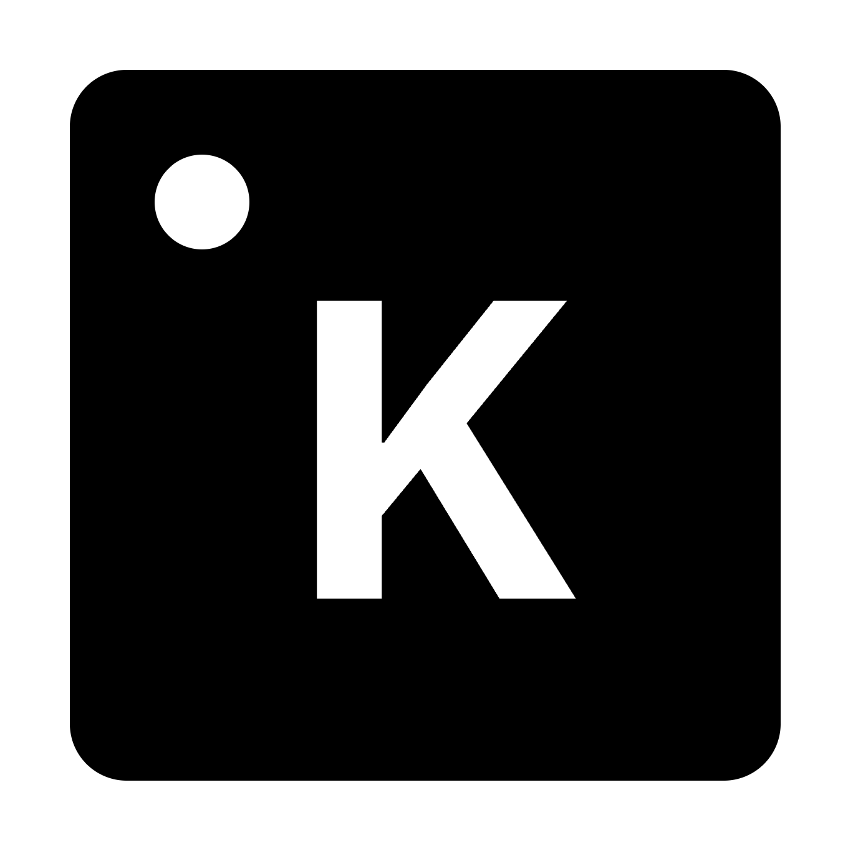
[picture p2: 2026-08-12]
pcb/art/kleist-labs-monogram.png

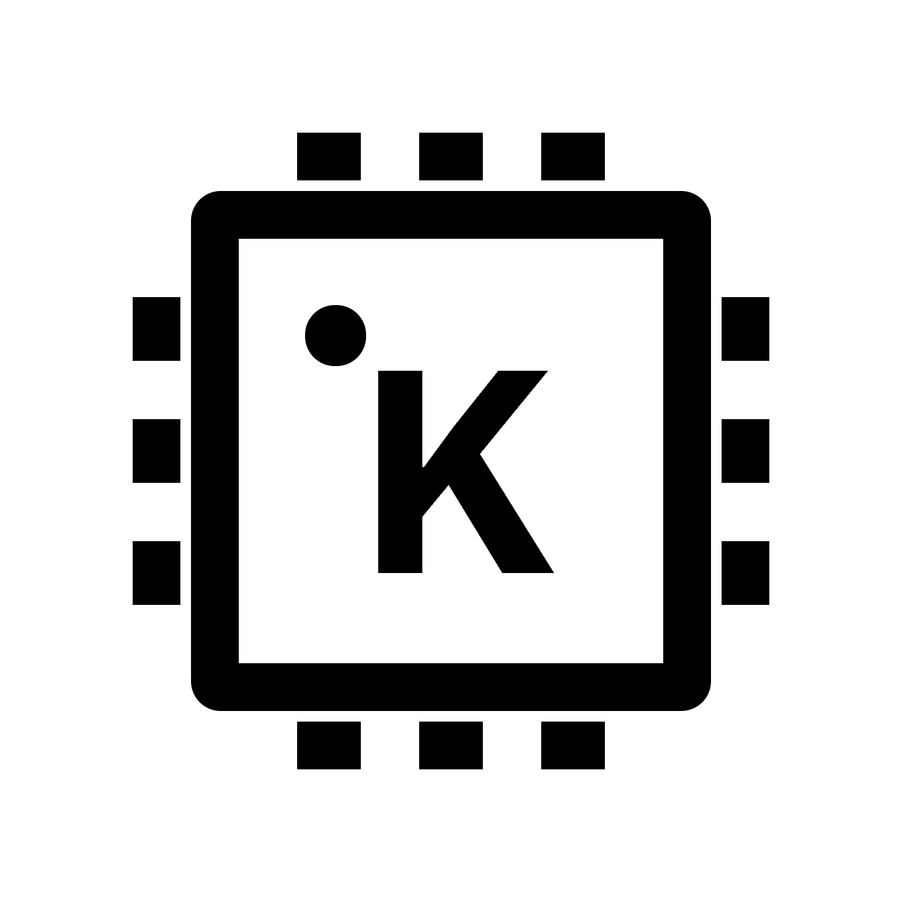
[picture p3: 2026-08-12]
pcb/art/kleist-labs-10a-symbol.png

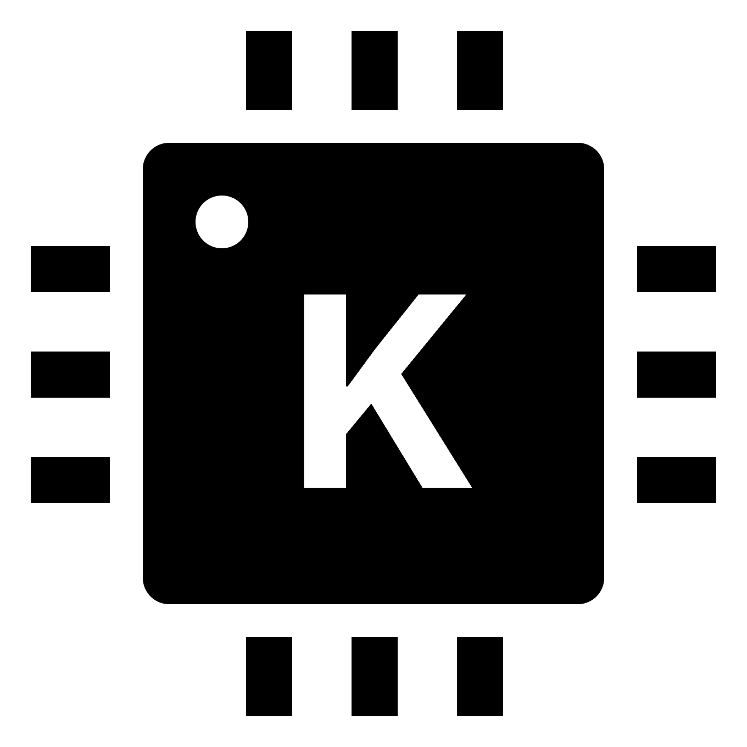
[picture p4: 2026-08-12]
pcb/art/kleist-labs-symbol.png

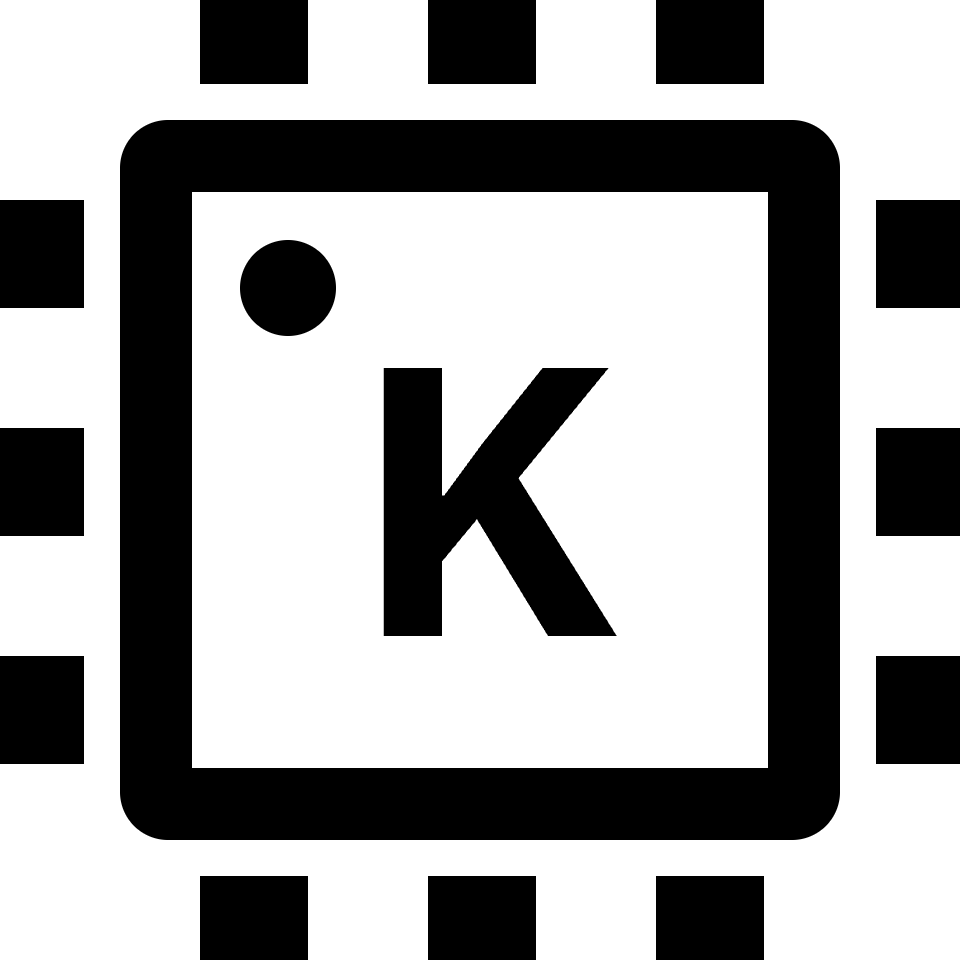
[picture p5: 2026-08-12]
pcb/art/kleist-labs-12a-8mm.png

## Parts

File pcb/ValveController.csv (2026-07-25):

Reference | Qty | Value | DNP | Exclude from BOM | Exclude from Board | MPN
C1 | 1 | 100uF |  |  |  | CL32A107MQVNNNE
C2,C7,C8 | 3 | 100nF |  |  |  | GRM155R71C104KA88D
C3 | 1 | 1uF |  |  |  | CL05A105KP5NNNC
C4,C5,C6 | 3 | 10uF |  |  |  | CL21A106KOFNNNE
CS1,CS2 | 2 | 22nF X2 |  |  |  | R463I22204001M
D1 | 1 | LED (active-low) |  |  |  | user stock (0402 LED)
D2,D3 | 2 | Z0103MN |  |  |  | Z0103MN 5AA4
D4,D5 | 2 | B5819W |  |  |  | B5819W-TP
F2 | 1 | 46205000000 |  |  |  | 46205000000
J2,J3 | 2 | 1990986 |  |  |  | 1990986
J8,J9,J10,J11,J12 | 5 | 1770966 |  |  |  | 1770966
J13 | 1 | USB4115-03-C |  |  |  | USB4115-03-C
Q3,Q4 | 2 | MOC3063S-TA1 |  |  |  | MOC3063S-TA1
R1 | 1 | B72210S0271K101 |  |  |  | B72210S0271K101
R2,R3,R7,R8,R9 | 5 | 10k |  |  |  | AC0402FR-0710KL
R4 | 1 | 1k |  |  |  | user stock (1k 0402)
R5,R6 | 2 | 5.1k |  |  |  | RC0402FR-075K1L
RG3,RG4 | 2 | 360 |  |  |  | RC0603FR-07360RL
RL1,RL2 | 2 | 180 |  |  |  | RC0402FR-07180RL
RS1,RS2 | 2 | 100 |  |  |  | ERJ-P08J101V
RS4,RS5,RS6,RS7,RS8 | 5 | 4700 |  |  |  | RC0402FR-074K7L
SW1 | 1 | TL9320AF400QG |  |  |  | TL9320AF400QG
U1 | 1 | IRM-03-5 |  |  |  | IRM-03-5
U2 | 1 | TLV75733P |  |  |  | TLV75733PDRVR
U5 | 1 | ESP32-C6-WROOM-1-N4 |  |  |  | ESP32-C6-WROOM-1-N4

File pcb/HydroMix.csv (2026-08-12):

Reference | Qty | Value | DNP | Exclude from BOM | Exclude from Board | MPN
C1 | 1 | 100uF |  |  |  | CL32A107MQVNNNE
C2,C7,C8,C14,C16,C17,C20 | 7 | 100nF |  |  |  | CL05B104KO5NNNC
C3,C15,C19 | 3 | 1uF |  |  |  | CL05A105KP5NNNC
C4,C5,C6 | 3 | 10uF |  |  |  | C0805C106K3PACTU
C9 | 1 | 4.7uF |  |  |  | GRM21BR71C475KE51K
C10,C11 | 2 | 2.2uF |  |  |  | GCM31CR71H225KA55L
C12 | 1 | 10nF |  |  |  | C0402C103K5RECAUTO
C13 | 1 | 82pF |  |  |  | GRM1555C1H820JA01D
C18 | 1 | 4.7nF X1/Y2 | DNP |  |  | R413F147050T1K
CS1,CS2 | 2 | 4.7nF X1/Y2 |  |  |  | R413F147050T1K
D2,D3 | 2 | Z0103MN |  |  |  | Z0103MN 5AA4
D4,D5 | 2 | MBR130LSFT1G |  |  |  | MBR130LSFT1G
D6 | 1 | RB160MM-60TR |  |  |  | RB160MM-60TR
D7 | 1 | BZT52B27 |  |  |  | BZT52B27
D8,D9,D10,D11,D12 | 5 | PEC3205CS |  |  |  | PEC3205CS_R1_00701
D18,D19 | 2 | SMF51CA |  |  |  | SMF51CA
D20,D21 | 2 | SMF33A |  |  |  | SMF33A
DS1 | 1 | KWM-20881AGB |  |  |  | KWM-20881AGB
F2 | 1 | 46205000000 |  |  |  | 46205000000
J2,J3,J14 | 3 | 1990986 |  |  |  | 1990986
J8,J9,J10,J11,J12 | 5 | 1770966 |  |  |  | 1770966
J13 | 1 | USB4145-03-0170-C |  |  |  | USB4145-03-0170-C
J15 | 1 | 1990999 |  |  |  | 1990999
L1 | 1 | 10uH |  |  |  | LSXND4040TKL100MDG
Q3,Q4 | 2 | MOC3063S-TA1 |  |  |  | MOC3063S-TA1
Q5 | 1 | CSD17313Q2 |  |  |  | CSD17313Q2
Q6,Q7 | 2 | CPC1035N |  |  |  | CPC1035NTR
R1 | 1 | B72210S0271K101 |  |  |  | B72210S0271K101
R2,R3,R7,R8,R9,R13,R16,R20,R21,R22,R24,R26,R27,R28,R29,R39 | 16 | 10k |  |  |  | AC0402FR-0710KL
R5,R6 | 2 | 5.1k |  |  |  | RC0402FR-075K1L
R10 | 1 | 249k |  |  |  | RC0402FR-07249KL
R11 | 1 | 13.3k |  |  |  | RC0402FR-0713K3L
R12,R34,R35,R36,R37,R38 | 6 | 100 |  |  |  | RC0402FR-07100RL
R14 | 1 | 2.2k |  |  |  | ERJ-P08J222V
R15,R17,R40,RS1,RS2 | 5 | 100 |  |  |  | ERJ-P08J101V
R18,R19,R23,R25 | 4 | 4.7k |  |  |  | RC0402FR-074K7L
R30,R31 | 2 | 1k |  |  |  | user stock (1k 0402)
R32,R33 | 2 | 100k |  |  |  | RC0402FR-07100KL
RG3,RG4 | 2 | 360 |  |  |  | RC0603FR-07360RL
RL1,RL2 | 2 | 180 |  |  |  | RC0402FR-07180RL
RL3,RL4 | 2 | 470 |  |  |  | RC0402FR-07470RL
RS4,RS5,RS6,RS7,RS8 | 5 | 4700 |  |  |  | RC0402FR-074K7L
SW1 | 1 | TL9320AF400QG |  |  |  | TL9320AF400QG
SW3 | 1 | A6S-1102-H |  |  |  | A6S-1102-H
U1 | 1 | IRM-03-5 |  |  |  | IRM-03-5
U2 | 1 | TLV75733P |  |  |  | TLV75733PDRVR
U5 | 1 | ESP32-C6-WROOM-1-N4 |  |  |  | ESP32-C6-WROOM-1-N4
U6 | 1 | TPS61040 |  |  |  | TPS61040DRVR
U7 | 1 | IS31FL3730 |  |  |  | IS31FL3730-QFLS2-TR
U8,U9 | 2 | HCPL-354-06AE |  |  |  | HCPL-354-06AE
U10 | 1 | USBLC6-2SC6 |  |  |  | USBLC6-2SC6

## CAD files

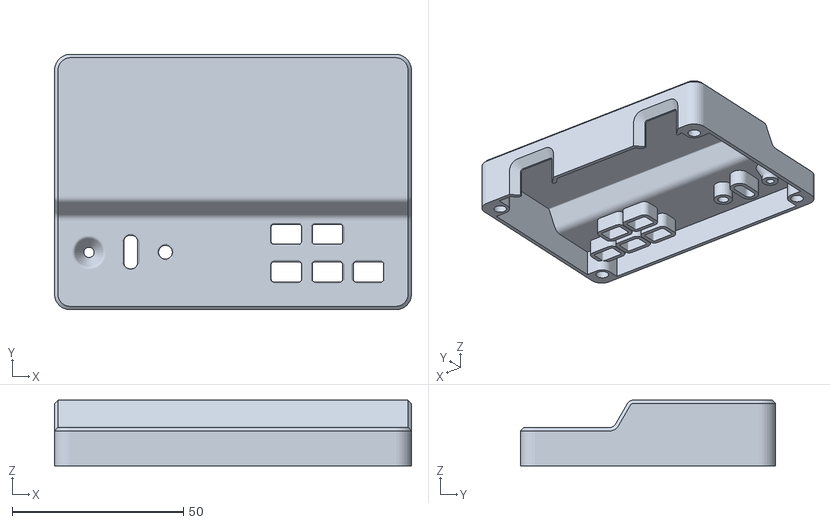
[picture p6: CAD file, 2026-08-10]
top.stl
104.1 x 74.5 x 19.2

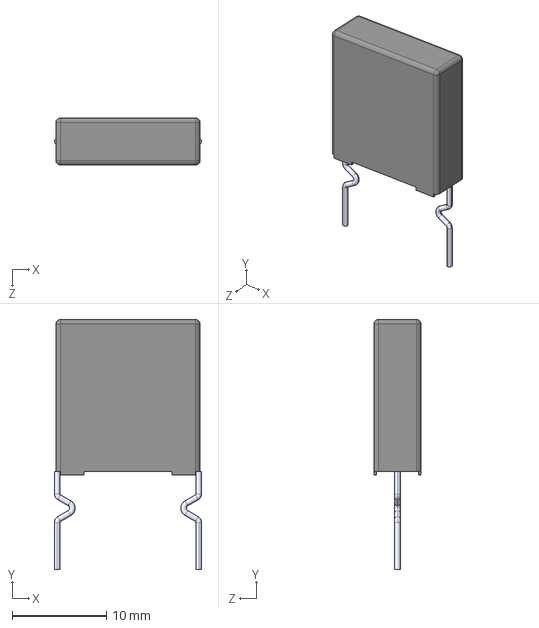
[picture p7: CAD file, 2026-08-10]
pcb/3dmodels/ECQUBAF472V5.step
15.6 x 26.5 x 5.00 mm

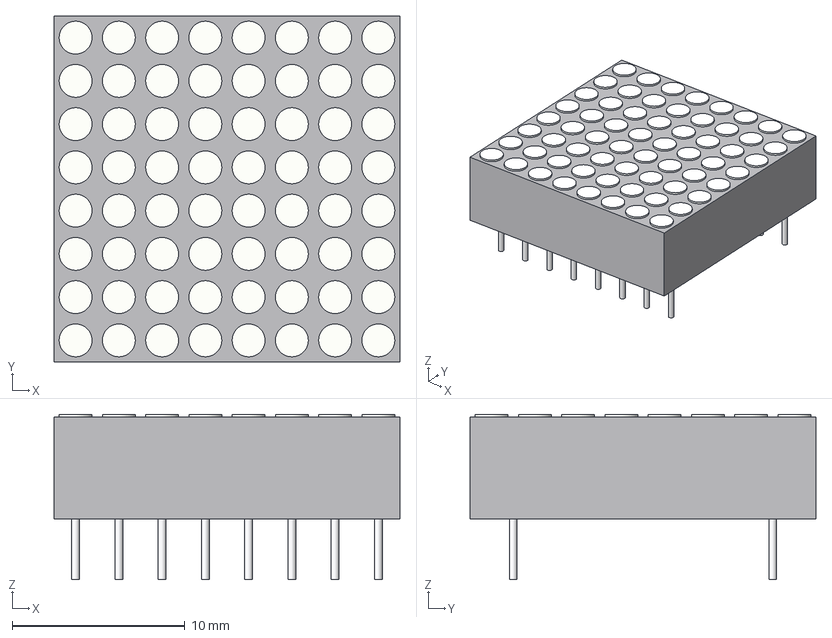
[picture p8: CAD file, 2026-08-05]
pcb/3dmodels/KWM-20881AGB.stp
20.0 x 20.0 x 9.55 mm
body_part
dots_part
pins_part

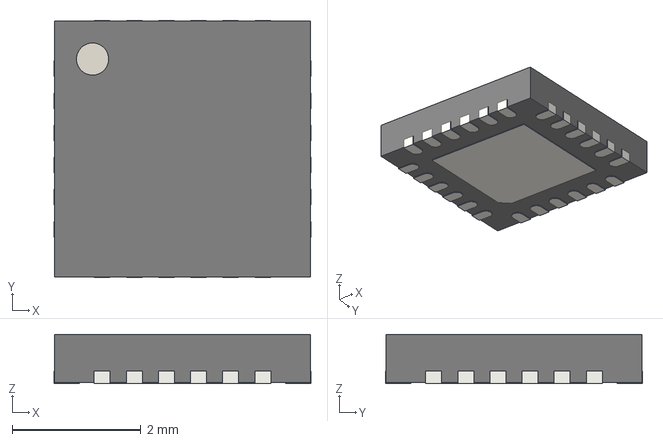
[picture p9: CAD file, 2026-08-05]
pcb/3dmodels/QFN-24-1EP_4x4mm_P0.5mm_EP2.5x2.5mm.step
4.00 x 4.00 x 0.77 mm

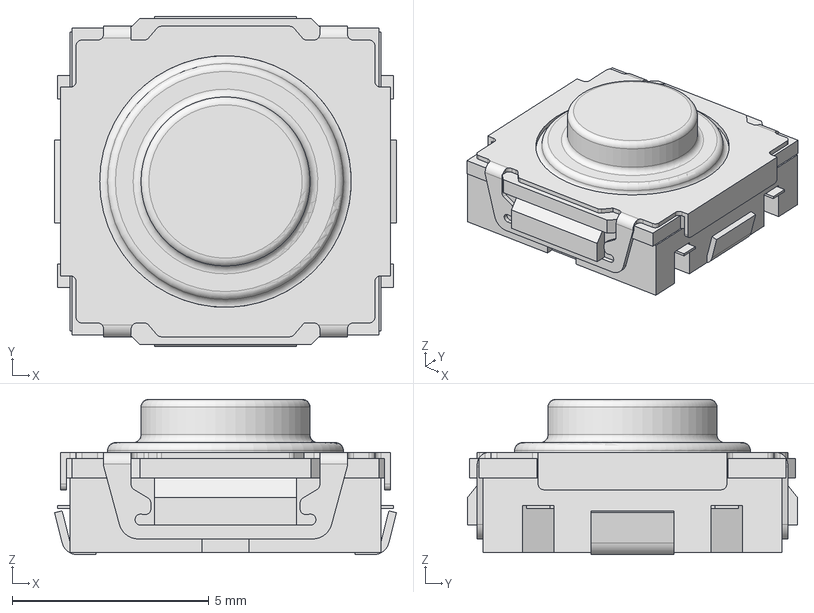
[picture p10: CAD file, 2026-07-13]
pcb/3dmodels/TL9320AF400QG.STEP
8.70 x 8.40 x 3.95 mm

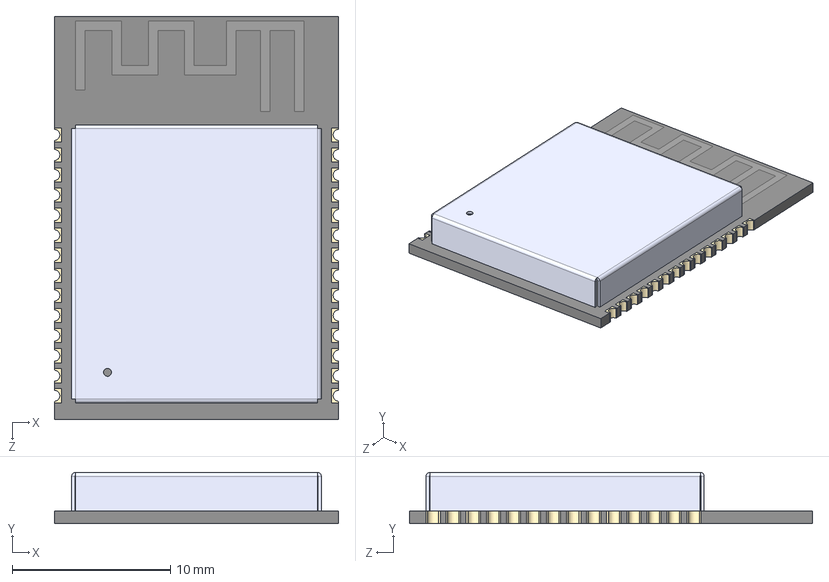
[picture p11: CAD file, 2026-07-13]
pcb/3dmodels/ESP32-C6-WROOM-1-N4.STEP
18.0 x 3.25 x 25.5 mm

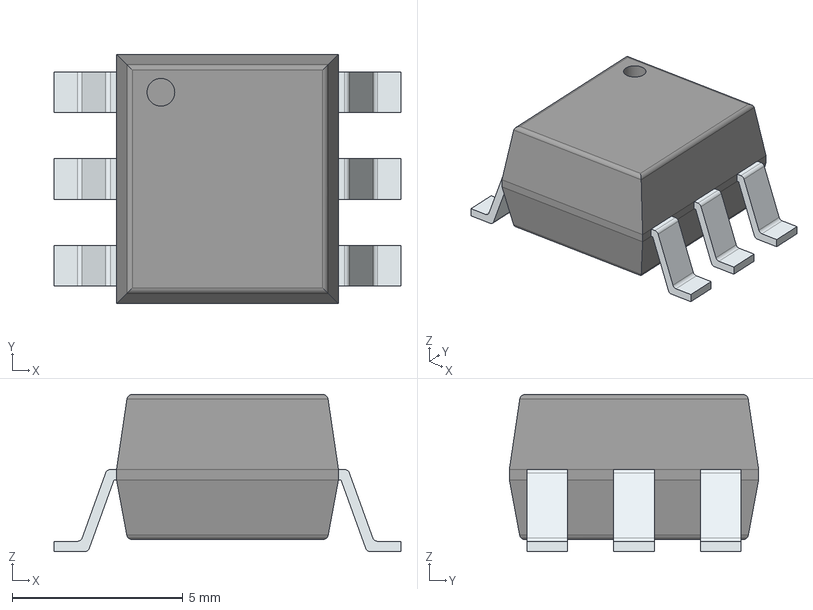
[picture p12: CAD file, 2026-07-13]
pcb/3dmodels/MOC3063S.stp
10.2 x 7.30 x 4.60 mm
PinsArrayLR

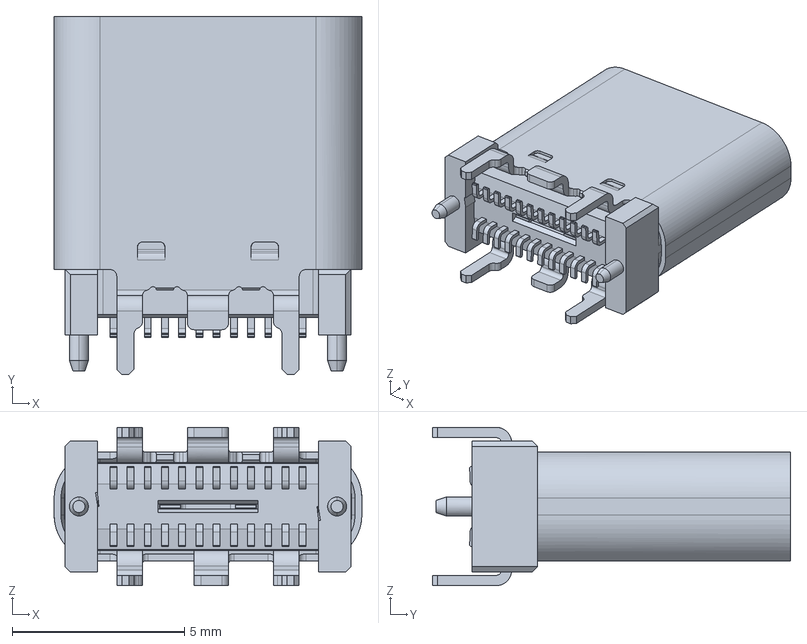
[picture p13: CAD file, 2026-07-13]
pcb/3dmodels/usb4115-03-c.stp
8.94 x 10.4 x 4.60 mm

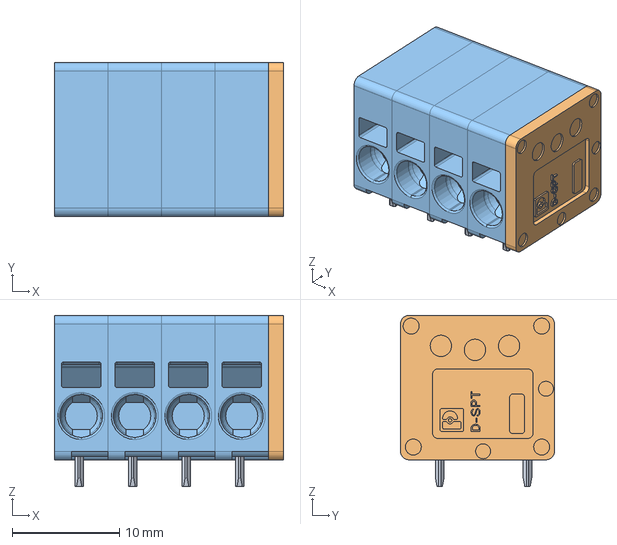
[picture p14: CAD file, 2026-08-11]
pcb/3dmodels/1990999.stp
21.4 x 14.4 x 16.0 mm

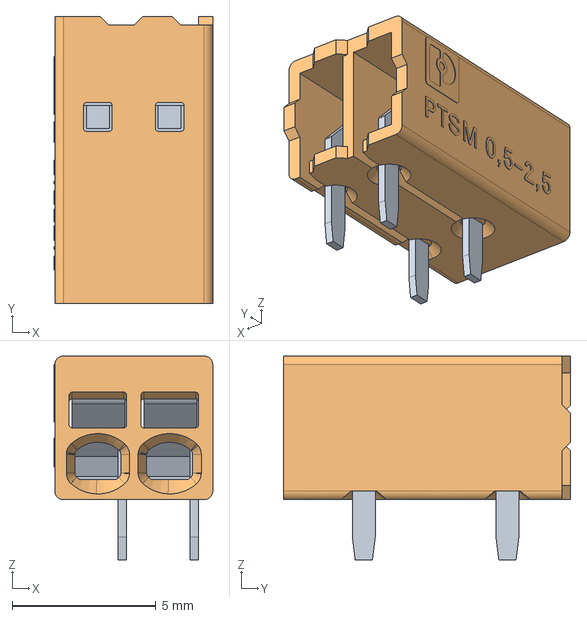
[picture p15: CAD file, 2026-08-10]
pcb/3dmodels/1770885.stp
5.52 x 10.0 x 7.10 mm

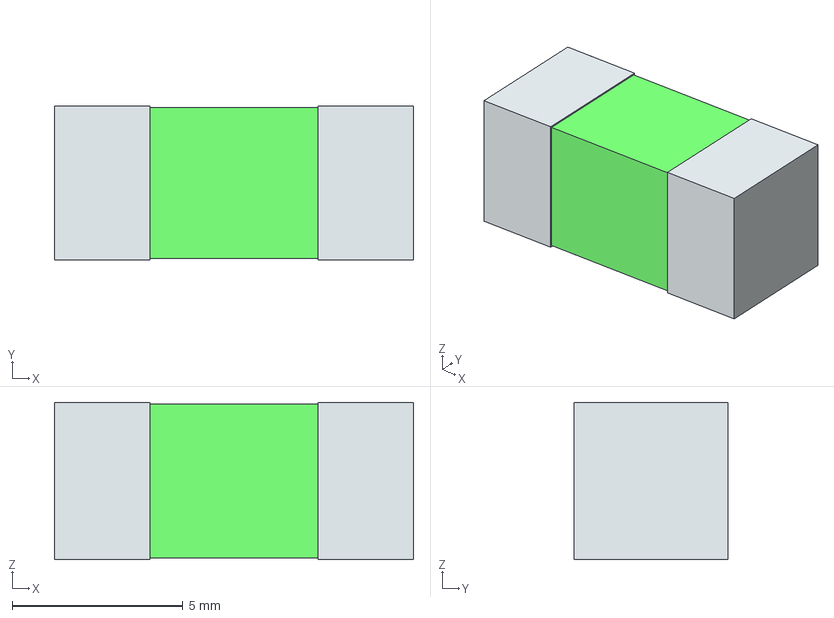
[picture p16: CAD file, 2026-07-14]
pcb/3dmodels/46205000000.stp
10.5 x 4.50 x 4.60 mm
term1
term2

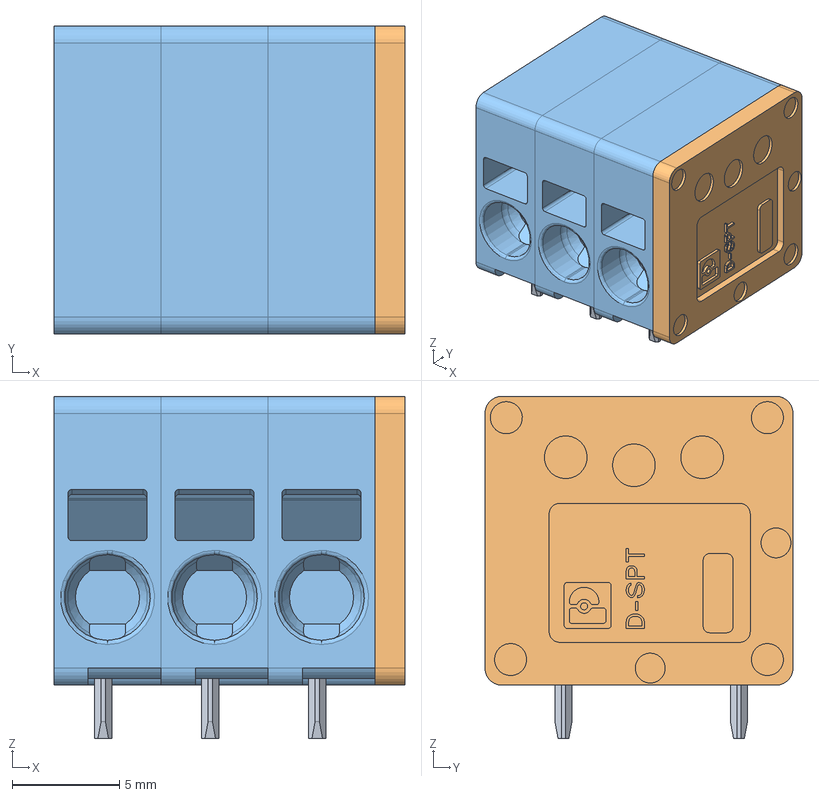
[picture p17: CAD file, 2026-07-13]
pcb/3dmodels/1990986.stp
16.4 x 14.4 x 16.0 mm

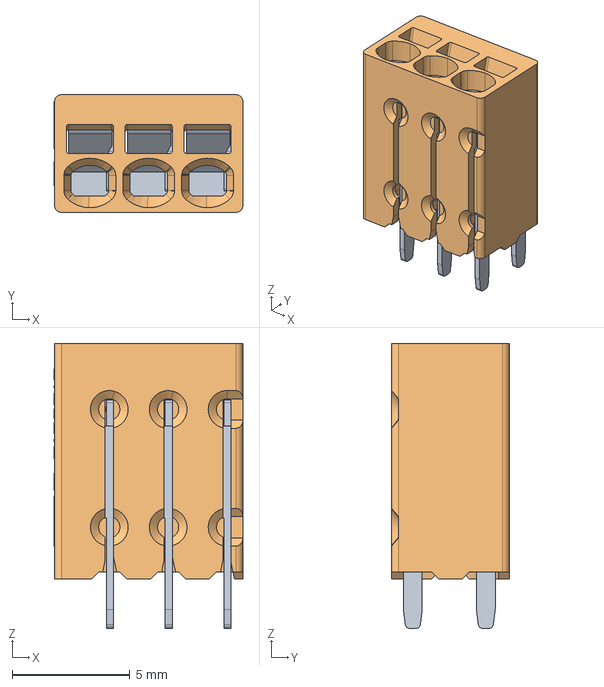
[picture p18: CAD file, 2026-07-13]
pcb/3dmodels/1770966.stp
8.02 x 5.00 x 12.1 mm

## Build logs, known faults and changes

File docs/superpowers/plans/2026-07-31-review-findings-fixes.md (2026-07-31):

# Review-Findings Fixes (1.2.1 → 1.3.0) Implementation Plan

> **For agentic workers:** REQUIRED SUB-SKILL: Use superpowers:subagent-driven-development (recommended) or superpowers:executing-plans to implement this plan task-by-task. Steps use checkbox (`- [ ]`) syntax for tracking.

**Goal:** Fix all 7 major + 5 minor + 3 nit findings from the 2026-07-31 firmware review of the 1.2.1 tree, ship as 1.3.0.

**Architecture:** Pure logic goes into `firmware/components/ctrl_core/` (host-tested, Unity). `firmware/main/` gets HW/stack wiring only. One new ctrl_core unit (`ota_gate`), one new NVS key (water_running, outside the cfg blob), one z2m converter change. Task 0 first commits the already-shipped 1.2.1 working tree so git history matches the binary on the live device.

**Tech Stack:** ESP-IDF 5.5.4 (`~/esp/esp-idf`), esp-zigbee-lib 1.6.8 / esp-zboss-lib 1.6.4, plain C11, Unity + CMake/ctest host suite, Python 3 (`tools/make_ota.py`).

## Global Constraints

- **Host tests build OUTSIDE the repo.** The repo already has 16 stray `firmware/test_host/build-*` dirs; do not add another. Canonical command (validated, 13/13 green):
  ```bash
  cmake -S firmware/test_host -B /tmp/vc-tests \
    -DFETCHCONTENT_SOURCE_DIR_UNITY=/Users/kleist/Sites/ValveController/firmware/test_host/build-121a/_deps/unity-src \
  && cmake --build /tmp/vc-tests -j8 \
  && ctest --test-dir /tmp/vc-tests --output-on-failure
  ```
  The `FETCHCONTENT_SOURCE_DIR_UNITY` override reuses the vendored Unity v2.6.0 already on disk — without it CMake hits the network.
- `firmware/test_host/CMakeLists.txt` **GLOBs** `test_*.c`. Adding a NEW test file requires re-running the `cmake -S ... -B ...` configure step (the command above does). `firmware/components/ctrl_core/CMakeLists.txt` GLOBs `*.c`, so new ctrl_core sources need no build-file edit.
- **Full target build (`idf.py build`) is a VERIFY step in the FINAL task only**, not per-task. `source ~/esp/esp-idf/export.sh` first.
- `sdkconfig` is gitignored. Source of truth is `firmware/sdkconfig.defaults`: `CONFIG_ESP_TASK_WDT_INIT=y`, `CONFIG_ESP_TASK_WDT_TIMEOUT_S=30`, `CONFIG_ESP_TASK_WDT_PANIC=y`, `CONFIG_BOOTLOADER_APP_ROLLBACK_ENABLE=y`.
- **Device is live on a household heating loop.** Every default chosen here is the safety-conservative one. Never leave the tree in a state where a mid-plan flash regresses live behaviour (this dictates the Task 4-before-Task 5 ordering; see Task 5).
- **NEVER run tests/builds directly from an engineer context** — delegate to a **test-runner** subagent.
- Commits: Angular convention. Always path-limited, one shell invocation:
  `git add -- <files> && git commit -m "msg" -- <same files>`. **Never blanket-stage** — `board.step`, `pcb/ValveController.kicad_pcb`, `pcb/ValveController.kicad_sch`, `pcb/3dmodels/`, `top.stl` are the owner's uncommitted work and must NOT be committed by any task.
- Max 5 files per task.
- **All line numbers in this plan are as-of the 1.2.1 tree committed in Task 0** and drift as earlier tasks land. Every edit step quotes the exact text to replace — **anchor on the quoted content, not the line number.** Notably `firmware/main/zigbee.c` is edited by Tasks 4, 6, 7, 9 and 12, and `firmware/main/control_task.c` by Tasks 2, 4 and 8.
- z2m converter lives at `z2m/valvectl.mjs`. **Deploying it to HAOS is out of scope** (see Non-goals).

## Non-goals (explicitly out of scope)

- Bench verifications: reporting `max_interval=0` semantics, thermostat setpoint writes above 30 °C, the Z2M `availability` setting.
- z2m converter climate/setpoint expose gap (`tz.thermostat_occupied_*_setpoint` handlers are wired but no `e.climate()` expose exists) — separate decision, Unresolved Q5.
- Deployment: USB flash, OTA staging to HAOS, Z2M converter/index install.
- `interlock.c:15` `both_error_count` is unreachable — **deliberately left in place** as a zero-cost safety net (Task 12 records the rationale, changes no code).

---

### Task 0: Commit the shipped 1.2.1 tree as-is

The current uncommitted firmware working tree is byte-for-byte what was OTA-delivered to the live device today. Commit it unchanged so git history matches the shipped artifact. **No code edits in this task.**

**Files:**
- Modify (commit only, no edits): `firmware/components/ctrl_core/sensor_policy.c`, `firmware/main/control_task.c`, `firmware/main/ota.c`, `firmware/test_host/test_sensor_policy.c`, `firmware/version.txt`, `firmware/README.md`

- [ ] **Step 1: Confirm exactly these six files, and nothing else, are staged**

```bash
git diff --stat -- firmware/README.md firmware/components/ctrl_core/sensor_policy.c \
  firmware/main/control_task.c firmware/main/ota.c \
  firmware/test_host/test_sensor_policy.c firmware/version.txt
```
Expected: exactly 6 files listed. `firmware/version.txt` must read `1.2.1`:
```bash
cat firmware/version.txt   # -> 1.2.1
```

- [ ] **Step 2: Confirm the owner's non-firmware changes are NOT in the commit set**

```bash
git status --short -- board.step pcb top.stl
```
Expected: `board.step`, `pcb/ValveController.kicad_pcb`, `pcb/ValveController.kicad_sch` still show ` M`, `pcb/3dmodels/`, `top.stl` still `??`. They must remain untouched after Step 3.

- [ ] **Step 3: Run the host suite on the unmodified tree**

Delegate to test-runner:
```bash
cmake -S firmware/test_host -B /tmp/vc-tests \
  -DFETCHCONTENT_SOURCE_DIR_UNITY=/Users/kleist/Sites/ValveController/firmware/test_host/build-121a/_deps/unity-src \
&& cmake --build /tmp/vc-tests -j8 \
&& ctest --test-dir /tmp/vc-tests --output-on-failure
```
Expected: `100% tests passed out of 13`.

- [ ] **Step 4: Commit**

```bash
git add -- firmware/README.md firmware/components/ctrl_core/sensor_policy.c \
  firmware/main/control_task.c firmware/main/ota.c \
  firmware/test_host/test_sensor_policy.c firmware/version.txt \
&& git commit -m "fix(fw): leaky fault-streak decay, OTA gate decoupled from probes; release 1.2.1" \
  -- firmware/README.md firmware/components/ctrl_core/sensor_policy.c \
     firmware/main/control_task.c firmware/main/ota.c \
     firmware/test_host/test_sensor_policy.c firmware/version.txt
```

- [ ] **Step 5: Verify the working tree still has the owner's PCB changes**

```bash
git status --short
```
Expected: `board.step`, `pcb/*` and `top.stl` entries survive; no `firmware/` entries except the untracked `.cache/` and `build-*/` dirs.

---

### Task 1: F5 — fault-streak decay needs 3 consecutive goods

`sensor_policy.c:22` forgives one fail after **2** consecutive goods, so break-even sits at a 33 % failure rate: `good,good,fail` repeating nets zero and a probe failing a third of its sweeps **never latches**. Raise the requirement to 3 consecutive goods (break-even 25 %).

**Files:**
- Modify: `firmware/components/ctrl_core/include/ctrl_core/sensor_policy.h`
- Modify: `firmware/components/ctrl_core/sensor_policy.c:18-22`
- Test: `firmware/test_host/test_sensor_policy.c`

**Interfaces:**
- Produces: `#define SENSOR_DECAY_AFTER 3` in `sensor_policy.h` — consecutive good reads required before each further good forgives one fail. `sensor_fault_update()` signature is unchanged.

- [ ] **Step 1: Rewrite the inverted test and add the 25 % break-even test**

In `firmware/test_host/test_sensor_policy.c`, **delete** the comment block at lines 60-73 and the whole `test_repeating_good_good_fail_never_latches` function (lines 74-85), and insert in their place:

```c
/* Leaky-bucket coverage. Rule under test (sensor_policy.c): fail_streak decays by 1
 * on every consecutive good read from the SENSOR_DECAY_AFTER'th onward; good_streak
 * resets to 0 on any bad read. Break-even is therefore one fail in
 * SENSOR_DECAY_AFTER+1 reads -- 25 % at the shipped value of 3. */

/* good,good,fail repeating (33 % failure) MUST latch: two goods never reach
 * SENSOR_DECAY_AFTER, so nothing is forgiven and fail_streak climbs by exactly 1
 * per cycle. Latches on the 3rd cycle's fail == the 9th sweep. Regression guard for
 * the 1.2.1 bug where the threshold was 2 and this pattern never latched at all. */
void test_repeating_good_good_fail_latches(void){
    sensor_fault_state_t s = {0};
    int cycles_to_latch = -1;
    for (int cycle = 0; cycle < 20 && cycles_to_latch < 0; ++cycle) {
        sensor_fault_update(&s, true);
        sensor_fault_update(&s, true);
        TEST_ASSERT_EQUAL_INT(cycle, s.fail_streak);        /* nothing forgiven */
        sensor_fault_update(&s, false);
        TEST_ASSERT_EQUAL_INT(cycle + 1, s.fail_streak);
        if (s.faulted) cycles_to_latch = cycle + 1;
    }
    TEST_ASSERT_EQUAL_INT(SENSOR_FAULT_AFTER, cycles_to_latch);
}

/* good,good,good,fail repeating (25 % failure, the break-even rate) must NEVER
 * latch: the 3rd consecutive good forgives that cycle's fail exactly, so
 * fail_streak oscillates 0 <-> 1 forever. */
void test_repeating_three_good_one_fail_never_latches(void){
    sensor_fault_state_t s = {0};
    for (int cycle = 0; cycle < 50; ++cycle) {
        sensor_fault_update(&s, true);
        sensor_fault_update(&s, true);
        sensor_fault_update(&s, true);
        TEST_ASSERT_EQUAL_INT(0, s.fail_streak);            /* 3rd good decays */
        sensor_fault_update(&s, false);
        TEST_ASSERT_EQUAL_INT(1, s.fail_streak);
        TEST_ASSERT_FALSE(s.faulted);
    }
}

/* A long good run keeps decaying once per read -- good_streak is not reset by a
 * decay, only by a bad read. Three fails then five goods must fully drain the
 * bucket (goods 3, 4 and 5 each forgive one). */
void test_long_good_run_decays_once_per_read(void){
    sensor_fault_state_t s = {0};
    sensor_fault_update(&s, false);
    sensor_fault_update(&s, false);            /* fail_streak 2, not yet latched */
    TEST_ASSERT_FALSE(s.faulted);
    sensor_fault_update(&s, true);
    sensor_fault_update(&s, true);
    TEST_ASSERT_EQUAL_INT(2, s.fail_streak);
    sensor_fault_update(&s, true);             /* 3rd consecutive good */
    TEST_ASSERT_EQUAL_INT(1, s.fail_streak);
    sensor_fault_update(&s, true);             /* 4th */
    TEST_ASSERT_EQUAL_INT(0, s.fail_streak);
    sensor_fault_update(&s, true);             /* 5th: floor at 0, no underflow */
    TEST_ASSERT_EQUAL_INT(0, s.fail_streak);
}
```

Update the registration in `main()`: replace
`RUN_TEST(test_repeating_good_good_fail_never_latches);` with
```c
    RUN_TEST(test_repeating_good_good_fail_latches);
    RUN_TEST(test_repeating_three_good_one_fail_never_latches);
    RUN_TEST(test_long_good_run_decays_once_per_read);
```

- [ ] **Step 2: Replace the remaining hardcoded 3s and stale comments in the same file (finding 13b + 15)**

In `test_single_good_does_not_clear_latched_fault`, change
`TEST_ASSERT_EQUAL_INT(3, s.fail_streak);   /* not zeroed by the single good read */` to:
```c
    TEST_ASSERT_EQUAL_INT(SENSOR_FAULT_AFTER, s.fail_streak);  /* not zeroed by the single good read */
```

In `test_clears_after_3_consecutive_goods`, change `TEST_ASSERT_TRUE(sensor_fault_update(&s, true));   /* 3rd good clears */` to:
```c
    TEST_ASSERT_TRUE(sensor_fault_update(&s, true));   /* SENSOR_CLEAR_AFTER'th good clears */
```

In `test_fail_fail_good_fail_latches`, replace its leading comment and the two magic 3s:
```c
/* fail,fail,good,fail: the single good read only reaches good_streak == 1, well short
 * of SENSOR_DECAY_AFTER, so it forgives nothing. The trailing fail pushes fail_streak
 * to SENSOR_FAULT_AFTER and latches -- a net-failing sensor (3 bad in 4 sweeps) must
 * latch. */
void test_fail_fail_good_fail_latches(void){
    sensor_fault_state_t s = {0};
    sensor_fault_update(&s, false);
    TEST_ASSERT_EQUAL_INT(1, s.fail_streak);
    sensor_fault_update(&s, false);
    TEST_ASSERT_EQUAL_INT(2, s.fail_streak);
    TEST_ASSERT_FALSE(s.faulted);
    sensor_fault_update(&s, true);
    TEST_ASSERT_EQUAL_INT(2, s.fail_streak);   /* 1 consecutive good < SENSOR_DECAY_AFTER */
    TEST_ASSERT_FALSE(s.faulted);
    sensor_fault_update(&s, false);
    TEST_ASSERT_EQUAL_INT(SENSOR_FAULT_AFTER, s.fail_streak);
    TEST_ASSERT_TRUE(s.faulted);
}
```

In `test_repeating_fail_fail_good_latches_within_a_few_cycles`, replace its leading comment:
```c
/* fail,fail,good repeating: the lone good never reaches SENSOR_DECAY_AFTER consecutive
 * (the next fail resets good_streak to 0 first), so decay never fires at all -- 
 * fail_streak climbs by 2 every cycle and a mostly-bad sensor latches almost
 * immediately (at the start of the 2nd cycle). */
```

- [ ] **Step 3: test-runner — expect `test_sensor_policy` to FAIL**

```bash
cmake -S firmware/test_host -B /tmp/vc-tests \
  -DFETCHCONTENT_SOURCE_DIR_UNITY=/Users/kleist/Sites/ValveController/firmware/test_host/build-121a/_deps/unity-src \
&& cmake --build /tmp/vc-tests -j8 \
&& ctest --test-dir /tmp/vc-tests --output-on-failure -R test_sensor_policy
```
Expected: FAIL — under the shipped 2-good rule the second good of cycle 1 already decays, so `test_repeating_good_good_fail_latches` aborts on its mid-cycle assert with `Expected 1 Was 0` (it never reaches the latch assertion), and `test_long_good_run_decays_once_per_read` fails with `Expected 2 Was 1` at the second good. `test_repeating_three_good_one_fail_never_latches` passes under both rules — it is the guard against over-correcting.

- [ ] **Step 4: Implement**

`firmware/components/ctrl_core/include/ctrl_core/sensor_policy.h` — add below `SENSOR_CLEAR_AFTER`:
```c
#define SENSOR_DECAY_AFTER  3         /* consecutive good reads before each further good forgives one fail */
```

`firmware/components/ctrl_core/sensor_policy.c` — replace lines 18-22 (the comment and the decay line):
```c
        /* Leaky decay of the fail-streak bucket. Precisely:
         *   - the first SENSOR_DECAY_AFTER-1 goods of a run forgive nothing;
         *   - every consecutive good from the SENSOR_DECAY_AFTER'th onward forgives
         *     exactly one earlier fail (fail_streak--), floored at 0;
         *   - good_streak is NOT reset by a decay, so a long good run keeps decaying
         *     once per read; only a bad read resets it to 0.
         * Break-even is therefore one fail in SENSOR_DECAY_AFTER+1 reads: 25 % at 3.
         * A worse-than-25 % failure rate still climbs to the latch threshold; a rarer
         * isolated glitch is forgiven and never accumulates. The 1.2.1 value of 2 put
         * break-even at 33 %, so a probe failing a third of its sweeps never latched. */
        if (s->good_streak >= SENSOR_DECAY_AFTER && s->fail_streak > 0) s->fail_streak--;
```

- [ ] **Step 5: test-runner — full host suite green**

```bash
cmake --build /tmp/vc-tests -j8 && ctest --test-dir /tmp/vc-tests --output-on-failure
```
Expected: `100% tests passed out of 13`.

- [ ] **Step 6: Commit**

```bash
git add -- firmware/components/ctrl_core/include/ctrl_core/sensor_policy.h \
  firmware/components/ctrl_core/sensor_policy.c firmware/test_host/test_sensor_policy.c \
&& git commit -m "fix(fw): require 3 consecutive goods to decay a fault streak (25% break-even)" \
  -- firmware/components/ctrl_core/include/ctrl_core/sensor_policy.h \
     firmware/components/ctrl_core/sensor_policy.c firmware/test_host/test_sensor_policy.c
```

---

### Task 2: F4 — extract the OTA validation gate and move it outside the WDT window

`control_task.c:81-84` validates the OTA image after 3 completed cycles ≈ 20 s — **inside** the 30 s task-WDT window, so the comment at `:25-29` and the README claim ("a hang trips the 30 s task WDT and reboots, which rolls back on its own") are inverted: the gate fires before the watchdog could ever catch a hang. Raise to 12 cycles (~110 s) and extract the one-shot logic into a host-testable ctrl_core function.

**Files:**
- Create: `firmware/components/ctrl_core/include/ctrl_core/ota_gate.h`
- Create: `firmware/components/ctrl_core/ota_gate.c`
- Create: `firmware/test_host/test_ota_gate.c`
- Modify: `firmware/main/control_task.c:25-29,81-84`
- Modify: `firmware/README.md:64-71`

**Interfaces:**
- Produces: `bool ota_gate_step(uint32_t *cycles, uint32_t threshold)` — call once per completed control cycle; returns `true` exactly once, on the call that brings `*cycles` up to `threshold`. `*cycles` saturates at `threshold` (never wraps, never fires twice). `threshold == 0` never fires.
- Produces: `#define OTA_GATE_CYCLES 12` in `control_task.c` (file-local).

- [ ] **Step 1: Write the failing test**

Create `firmware/test_host/test_ota_gate.c`:
```c
#include "unity.h"
#include "ctrl_core/ota_gate.h"

void setUp(void){} void tearDown(void){}

/* Fires exactly once, on the call that reaches the threshold -- never before. */
void test_fires_exactly_at_threshold(void){
    uint32_t c = 0;
    for (uint32_t i = 1; i < 12; ++i)
        TEST_ASSERT_FALSE(ota_gate_step(&c, 12));
    TEST_ASSERT_TRUE(ota_gate_step(&c, 12));          /* 12th call */
    TEST_ASSERT_EQUAL_UINT32(12, c);
}

/* Never fires again, and the counter saturates rather than wrapping. */
void test_never_fires_again_and_saturates(void){
    uint32_t c = 0;
    for (int i = 0; i < 12; ++i) ota_gate_step(&c, 12);
    for (int i = 0; i < 1000; ++i) TEST_ASSERT_FALSE(ota_gate_step(&c, 12));
    TEST_ASSERT_EQUAL_UINT32(12, c);
}

/* Threshold 1 fires on the very first call, then never again. */
void test_threshold_one_fires_immediately(void){
    uint32_t c = 0;
    TEST_ASSERT_TRUE(ota_gate_step(&c, 1));
    TEST_ASSERT_FALSE(ota_gate_step(&c, 1));
    TEST_ASSERT_EQUAL_UINT32(1, c);
}

/* Threshold 0 must never fire -- a mis-set constant must not validate an image
 * instantly (that would silently disable rollback protection). */
void test_threshold_zero_never_fires(void){
    uint32_t c = 0;
    for (int i = 0; i < 10; ++i) TEST_ASSERT_FALSE(ota_gate_step(&c, 0));
    TEST_ASSERT_EQUAL_UINT32(0, c);
}

int main(void){
    UNITY_BEGIN();
    RUN_TEST(test_fires_exactly_at_threshold);
    RUN_TEST(test_never_fires_again_and_saturates);
    RUN_TEST(test_threshold_one_fires_immediately);
    RUN_TEST(test_threshold_zero_never_fires);
    return UNITY_END();
}
```

- [ ] **Step 2: test-runner — expect configure/compile FAIL**

New test file ⇒ the CMake **configure** step must re-run to pick it up via the GLOB:
```bash
rm -rf /tmp/vc-tests && cmake -S firmware/test_host -B /tmp/vc-tests \
  -DFETCHCONTENT_SOURCE_DIR_UNITY=/Users/kleist/Sites/ValveController/firmware/test_host/build-121a/_deps/unity-src \
&& cmake --build /tmp/vc-tests -j8
```
Expected: FAIL — `fatal error: ctrl_core/ota_gate.h: No such file or directory`.

- [ ] **Step 3: Implement the ctrl_core unit**

Create `firmware/components/ctrl_core/include/ctrl_core/ota_gate.h`:
```c
#pragma once
#include "ctrl_core/types.h"

/* One-shot cycle counter for the OTA rollback-validation gate.
 *
 * Lives here rather than inline in control_task.c so the "fires exactly once, and
 * only at the threshold" property is host-testable: getting it wrong either
 * validates an image early (silently defeating rollback protection) or never
 * validates it (rollback loop). Neither failure is observable on a bench without
 * performing a real OTA.
 *
 * Call once per completed control cycle. *cycles saturates at threshold, so it
 * never wraps and never fires a second time. threshold == 0 never fires. */
bool ota_gate_step(uint32_t *cycles, uint32_t threshold);
```

Create `firmware/components/ctrl_core/ota_gate.c`:
```c
#include "ctrl_core/ota_gate.h"

bool ota_gate_step(uint32_t *cycles, uint32_t threshold){
    if (*cycles >= threshold) return false;   /* already fired, or threshold 0 */
    (*cycles)++;
    return *cycles == threshold;
}
```

No CMake edits needed: `components/ctrl_core/CMakeLists.txt` GLOBs `*.c`, `test_host/CMakeLists.txt` GLOBs both `test_*.c` and `../components/ctrl_core/*.c`.

- [ ] **Step 4: test-runner — full host suite green (now 14 tests)**

```bash
cmake --build /tmp/vc-tests -j8 && ctest --test-dir /tmp/vc-tests --output-on-failure
```
Expected: `100% tests passed out of 14`.

- [ ] **Step 5: Wire it into control_task.c**

Add the include after `#include "ota.h"` (line 10):
```c
#include "ctrl_core/ota_gate.h"
```

Replace lines 25-29 (the comment block and `static uint8_t s_cycles_completed = 0;`):
```c
/* Completed control cycles, saturating at OTA_GATE_CYCLES (see ctrl_core/ota_gate.h).
 * Sensor faults are a property of the plant wiring, not of the image, so OTA
 * validation must not wait on fault-free probes. What this gate DOES prove is that
 * the control task is still looping -- and only if it takes longer than the task
 * watchdog: OTA_GATE_CYCLES * CYCLE_MS is ~110 s, comfortably OUTSIDE the 30 s window
 * (CONFIG_ESP_TASK_WDT_TIMEOUT_S=30, panic on), so a hung control task trips the WDT
 * -> reset -> rollback long before this gate could validate. At the previous 3 cycles
 * (~20 s) the gate fired INSIDE the watchdog window and therefore proved nothing. */
#define OTA_GATE_CYCLES 12
static uint32_t s_cycles_completed = 0;
```

Replace lines 79-84 (the fast-path comment and the `if (s_cycles_completed < 3)` block):
```c
        /* OTA validation fast path: don't let a missing/faulted probe delay validation
         * all the way out to the 10-minute fallback timer in ota.c. */
        if (ota_gate_step(&s_cycles_completed, OTA_GATE_CYCLES)) ota_note_good_sweep();
```

- [ ] **Step 6: Fix the inverted README claim**

In `firmware/README.md`, replace list item 2 of the OTA validation section (lines 68-71):
```markdown
  2. `OTA_GATE_CYCLES` (12) completed control cycles regardless of sensor faults —
     sensor faults are a plant-wiring property, not an image property. 12 cycles at
     the 10 s control period is ~110 s, deliberately **longer** than the 30 s task
     watchdog timeout (`CONFIG_ESP_TASK_WDT_TIMEOUT_S=30`, panic on): a control task
     that hangs trips the watchdog and reboots — rolling back — *before* this gate
     could ever validate the image. (1.2.1 used 3 cycles ≈ 20 s, which fired inside
     the watchdog window and so proved nothing.)
```

- [ ] **Step 7: test-runner — suite still green**

```bash
ctest --test-dir /tmp/vc-tests --output-on-failure
```
Expected: `100% tests passed out of 14`.

- [ ] **Step 8: Commit**

```bash
git add -- firmware/components/ctrl_core/include/ctrl_core/ota_gate.h \
  firmware/components/ctrl_core/ota_gate.c firmware/test_host/test_ota_gate.c \
  firmware/main/control_task.c firmware/README.md \
&& git commit -m "fix(fw): move OTA validation gate outside the 30 s WDT window (12 cycles), extract to ctrl_core" \
  -- firmware/components/ctrl_core/include/ctrl_core/ota_gate.h \
     firmware/components/ctrl_core/ota_gate.c firmware/test_host/test_ota_gate.c \
     firmware/main/control_task.c firmware/README.md
```

---

### Task 3: F8 — freeze the supply alarm while the supply probe is faulted

`control.c:88` runs `alarm_supply_step()` unconditionally. With `faults.supply` set, `in->t_supply` is the last-good value — or `0.0` straight from BSS if the probe never read once. `0.0 <= ALARM_SUPPLY_LOW (15.5)` latches a **false freeze alarm** after the dwell; a frozen in-band value **falsely clears** a real one.

**Files:**
- Modify: `firmware/components/ctrl_core/control.c:87-88`
- Test: `firmware/test_host/test_control.c`

**Interfaces:**
- Consumes: `alarm_state_t` fields `alarmed`, `out_of_bounds`, `oob_since_ms` (`ctrl_core/alarm.h`), already reachable via `s->alarm`.
- Produces: no signature change. `control_out_t.supply_alarm` now holds its last value while `in->faults.supply` is set.

- [ ] **Step 1: Write the failing tests**

Append to `firmware/test_host/test_control.c`, before `main()`:
```c
/* Supply probe faulted: t_supply is stale or BSS-zero, so the freeze alarm must not
 * latch on it. 0.0 C is <= ALARM_SUPPLY_LOW and would otherwise alarm after dwell. */
void test_supply_fault_blocks_false_freeze_alarm(void){
    in.faults.supply = true;
    in.t_supply = 0.0f;
    control_out_t o = control_step(&st, &in, &cfg, 0);
    TEST_ASSERT_FALSE(o.supply_alarm);
    o = control_step(&st, &in, &cfg, 600000);        /* 10 min, twice the 5 min dwell */
    TEST_ASSERT_FALSE(o.supply_alarm);
}

/* A real alarm must survive the probe subsequently failing -- a frozen in-band value
 * must not clear it. */
void test_supply_fault_holds_existing_alarm(void){
    in.t_supply = 37.0f;
    control_step(&st, &in, &cfg, 0);
    control_out_t o = control_step(&st, &in, &cfg, 300000);
    TEST_ASSERT_TRUE(o.supply_alarm);                /* dwell met -> alarmed */
    in.faults.supply = true; in.t_supply = 30.0f;    /* frozen, in the clear band */
    o = control_step(&st, &in, &cfg, 310000);
    TEST_ASSERT_TRUE(o.supply_alarm);                /* must NOT falsely clear */
}

/* The excursion dwell re-arms clean on fault clear: an out-of-bounds reading right
 * after recovery must serve a fresh full dwell, not inherit stale elapsed time. */
void test_supply_fault_rearms_dwell_on_recovery(void){
    in.faults.supply = true;
    in.t_supply = 37.0f;
    control_step(&st, &in, &cfg, 0);
    control_step(&st, &in, &cfg, 600000);            /* 10 min faulted, no dwell accrues */
    in.faults.supply = false;
    control_out_t o = control_step(&st, &in, &cfg, 610000);
    TEST_ASSERT_FALSE(o.supply_alarm);               /* dwell restarts here */
    o = control_step(&st, &in, &cfg, 890000);        /* +280 s, still < 300 s */
    TEST_ASSERT_FALSE(o.supply_alarm);
    o = control_step(&st, &in, &cfg, 910001);        /* +300.001 s -> alarm */
    TEST_ASSERT_TRUE(o.supply_alarm);
}
```

Register in `main()`:
```c
    RUN_TEST(test_supply_fault_blocks_false_freeze_alarm);
    RUN_TEST(test_supply_fault_holds_existing_alarm);
    RUN_TEST(test_supply_fault_rearms_dwell_on_recovery);
```

- [ ] **Step 2: test-runner — expect `test_control` to FAIL**

```bash
ctest --test-dir /tmp/vc-tests --output-on-failure -R test_control
```
Expected: FAIL — `test_supply_fault_blocks_false_freeze_alarm` asserts TRUE where FALSE expected at the 600000 step (0.0 °C latched a freeze alarm).

- [ ] **Step 3: Implement**

In `firmware/components/ctrl_core/control.c`, replace lines 87-88:
```c
    /* Telemetry (always). */
    o.supply_alarm = alarm_supply_step(&s->alarm, in->t_supply, cfg->alarm_dwell_ms, now);
```
with:
```c
    /* Telemetry (always). The supply freeze alarm is only meaningful on a LIVE supply
     * reading: with the probe faulted, in->t_supply is the last-good value, or 0.0
     * straight from BSS if it never read once. 0.0 <= ALARM_SUPPLY_LOW would latch a
     * false freeze alarm after the dwell, and a frozen in-band value would falsely
     * clear a real one. So hold the current alarm state and re-arm the excursion dwell,
     * making it restart clean when the probe recovers. */
    if (in->faults.supply){
        s->alarm.out_of_bounds = false;
        s->alarm.oob_since_ms  = now;
        o.supply_alarm = s->alarm.alarmed;
    } else {
        o.supply_alarm = alarm_supply_step(&s->alarm, in->t_supply, cfg->alarm_dwell_ms, now);
    }
```

- [ ] **Step 4: test-runner — full host suite green**

```bash
cmake --build /tmp/vc-tests -j8 && ctest --test-dir /tmp/vc-tests --output-on-failure
```
Expected: `100% tests passed out of 14`.

- [ ] **Step 5: Commit**

```bash
git add -- firmware/components/ctrl_core/control.c firmware/test_host/test_control.c \
&& git commit -m "fix(fw): hold supply freeze alarm while the supply probe is faulted" \
  -- firmware/components/ctrl_core/control.c firmware/test_host/test_control.c
```

---

### Task 4: F7a + F12 — passive link liveness, and volatile cross-task state

**Ordering note (deliberate deviation from "ctrl_core first"):** this `main/` task MUST land **before** Task 5. Task 5 makes the cooling dew guard fire purely on `link_last_seen_ms`. Today that timestamp is only refreshed by ZDO signals, so shipping Task 5 first would let a long-joined device with no ZDO events look "quiet for 30 min" and spuriously raise the cooling setpoint. This task makes the timestamp truthful first, and on its own is a strict no-op-or-safer change (refreshing the timestamp more often only makes the *existing* guard less likely to fire).

**Files:**
- Modify: `firmware/main/control_task.h`
- Modify: `firmware/main/control_task.c:15-24,99`
- Modify: `firmware/main/zigbee.c:448-453`

**Interfaces:**
- Produces: `void control_task_note_link_activity(void)` — refreshes `s_link_seen` to now. Called from `zigbee.c`'s `action_handler` on every inbound core action callback. Task 5's `cooling_link_guard()` consumes the resulting `control_in_t.link_last_seen_ms`.

- [ ] **Step 1: Declare the new setter**

In `firmware/main/control_task.h`, add after `void control_task_set_link(bool up, uint32_t last_seen_ms);`:
```c
void        control_task_note_link_activity(void);   /* refresh liveness on inbound ZCL traffic */
```

- [ ] **Step 2: Make the cross-task statics volatile (F12) and add the setter (F7a)**

In `firmware/main/control_task.c`, replace lines 15-24:
```c
/* Cross-task state. Written by the Zigbee stack task (attr_cb, signal handler) and the
 * console task, read by the control loop -- and s_mode/s_alarm/s_faults the other way
 * round. volatile matches the ui.c:13 idiom for exactly this pattern. It is NOT
 * atomicity, but each of these is a single naturally-aligned word on RV32, and volatile
 * is what stops the compiler caching them in a register across the 10 s loop. */
static volatile ctrl_mode_t s_mode = MODE_IDLE;
static volatile bool     s_alarm = false;
static volatile uint16_t s_faults = 0;
static volatile bool     s_water_running = false;      /* HA enables regulation */
static volatile bool     s_link_up = false;
static volatile uint32_t s_link_seen = 0;
/* One-shot: set when an AnalogOutput manual override write is accepted (zigbee.c),
 * cleared on any water_running transition. While set, the OFF-park loop below leaves
 * the valve alone (spec §4.5: write supersedes park_pos until water_running ON or reboot). */
static volatile bool s_override_active = false;
```
(`s_ctrl` and `s_cycles_completed` stay non-volatile — both are touched only by the control loop, and `ota_gate_step()` takes a plain `uint32_t *`.)

Replace the one-line `control_task_set_link` definition near the end of the file —
```c
void control_task_set_link(bool up, uint32_t seen){ s_link_up = up; s_link_seen = seen; }
```
— with the two functions below:
```c
void control_task_set_link(bool up, uint32_t seen){
    /* seen BEFORE up: a reader that interleaves then sees a stale timestamp alongside
     * the new link state, never a fresh timestamp alongside the old one. The cooling
     * dew guard keys off the timestamp, and "older than it really is" errs toward
     * raising the cooling setpoint -- less cooling, the safe direction. */
    s_link_seen = seen;
    s_link_up = up;
}

/* Passive liveness. ZDO signals alone are not enough: a Router whose coordinator dies
 * silently gets no LEAVE and no failed STEERING, so s_link_up stays true forever. Any
 * inbound ZCL action is positive proof the coordinator is still talking to us. */
void control_task_note_link_activity(void){ s_link_seen = now_ms(); }
```

- [ ] **Step 3: Call it from the Zigbee action handler**

In `firmware/main/zigbee.c`, replace `action_handler` (lines 448-453):
```c
static esp_err_t action_handler(esp_zb_core_action_callback_id_t id, const void *msg)
{
    /* Any inbound core action -- attribute write, OTA block, reporting-config, command
     * callback -- proves the coordinator is alive. This is the broadest hook the stack
     * offers; plain attribute READS are answered inside the stack and do NOT reach here,
     * so the liveness signal is only as good as the traffic Z2M actually generates
     * (see Unresolved Q3: availability polling). */
    control_task_note_link_activity();
    if (id == ESP_ZB_CORE_SET_ATTR_VALUE_CB_ID)    return attr_cb(msg);
    if (id == ESP_ZB_CORE_OTA_UPGRADE_VALUE_CB_ID) return ota_zcl_handle(msg);
    return ESP_OK;
}
```

- [ ] **Step 4: test-runner — host suite unaffected but must still be green**

`main/` is not host-compiled; this confirms nothing regressed.
```bash
ctest --test-dir /tmp/vc-tests --output-on-failure
```
Expected: `100% tests passed out of 14`.

- [ ] **Step 5: Commit**

```bash
git add -- firmware/main/control_task.h firmware/main/control_task.c firmware/main/zigbee.c \
&& git commit -m "fix(fw): track inbound ZCL traffic as link liveness; mark cross-task state volatile" \
  -- firmware/main/control_task.h firmware/main/control_task.c firmware/main/zigbee.c
```

---

### Task 5: F7 — cooling dew guard triggers on traffic silence, not on `link_up`

`alarm.c:21` requires `!link_up`, but `s_link_up` only changes on ZDO signals. A Router whose coordinator dies silently never gets one — so the guard is unreachable in its single most likely scenario. Drop the `link_up` requirement: silence for `LINK_LOSS_COOLING_MS` is the trigger, and Task 4 made that timestamp reflect real traffic.

**Files:**
- Modify: `firmware/components/ctrl_core/include/ctrl_core/alarm.h`
- Modify: `firmware/components/ctrl_core/alarm.c:19-24`
- Modify: `firmware/components/ctrl_core/control.c:108-109`
- Modify: `firmware/components/ctrl_core/include/ctrl_core/control.h` (comment only)
- Test: `firmware/test_host/test_alarm.c`

**Interfaces:**
- Produces: `float cooling_link_guard(float cool_setpoint, ctrl_mode_t mode, uint32_t last_seen_ms, uint32_t now_ms)` — the `bool link_up` parameter is **removed**. `control_in_t.link_up` is kept (still set by `control_task.c`, still reported) but is no longer consumed by the guard; `control.h` records that explicitly.

- [ ] **Step 1: Update the tests to the new signature and add the silent-coordinator case**

In `firmware/test_host/test_alarm.c`, replace the two link-guard tests:
```c
/* Cooling dew guard: 30 min without inbound traffic in COOLING raises setpoint to 21.
 * This is the silently-dead-coordinator case -- there is no ZDO signal to key off, so
 * traffic silence alone must be enough. */
void test_link_guard_raises(void){
    TEST_ASSERT_EQUAL_FLOAT(21.0f, cooling_link_guard(18.0f, MODE_COOLING, 0, 1800000));
}

/* Recent traffic keeps the guard inactive no matter how long the device has been up. */
void test_link_guard_inactive_when_traffic_recent(void){
    TEST_ASSERT_EQUAL_FLOAT(18.0f, cooling_link_guard(18.0f, MODE_COOLING, 86400000u, 86401000u));
}

/* Inactive in heating, inside the window, at boot, and it never LOWERS a setpoint. */
void test_link_guard_inactive(void){
    TEST_ASSERT_EQUAL_FLOAT(35.0f, cooling_link_guard(35.0f, MODE_HEATING, 0, 1800000));
    TEST_ASSERT_EQUAL_FLOAT(18.0f, cooling_link_guard(18.0f, MODE_COOLING, 0, 1799000));
    TEST_ASSERT_EQUAL_FLOAT(18.0f, cooling_link_guard(18.0f, MODE_COOLING, 0, 0));
    TEST_ASSERT_EQUAL_FLOAT(24.0f, cooling_link_guard(24.0f, MODE_COOLING, 0, 1800000));
}
```

Register the new one in `main()`, after `RUN_TEST(test_link_guard_raises);`:
```c
    RUN_TEST(test_link_guard_inactive_when_traffic_recent);
```

- [ ] **Step 2: test-runner — expect compile FAIL**

```bash
ctest --test-dir /tmp/vc-tests --output-on-failure -R test_alarm
```
Expected: build FAIL — too few arguments to `cooling_link_guard`.

- [ ] **Step 3: Implement**

`firmware/components/ctrl_core/include/ctrl_core/alarm.h` — replace the declaration:
```c
/* Autonomous dew-point guard. Raises the cooling setpoint toward LINK_LOSS_COOL_SETPOINT
 * once we have not heard from the coordinator for LINK_LOSS_COOLING_MS, so an unattended
 * device cannot keep chilling a floor below dew point. Deliberately NOT gated on a ZDO
 * link-down signal: a Router whose coordinator dies silently never emits one, which is
 * precisely the scenario this exists for. last_seen_ms is refreshed by inbound ZCL
 * traffic AND by join/leave signals (control_task_note_link_activity / _set_link).
 * Only ever raises the setpoint -- never lowers it. */
float cooling_link_guard(float cool_setpoint, ctrl_mode_t mode,
                         uint32_t last_seen_ms, uint32_t now_ms);
```

`firmware/components/ctrl_core/alarm.c` — replace lines 19-24:
```c
float cooling_link_guard(float cool_setpoint, ctrl_mode_t mode,
                         uint32_t last_seen_ms, uint32_t now){
    if (mode == MODE_COOLING && (now - last_seen_ms) >= LINK_LOSS_COOLING_MS)
        return fmaxf(cool_setpoint, LINK_LOSS_COOL_SETPOINT);
    return cool_setpoint;
}
```

`firmware/components/ctrl_core/control.c` — replace lines 108-109:
```c
    float eff_cool = cooling_link_guard(cfg->cool_setpoint, mode,
                                        in->link_last_seen_ms, now);
```

`firmware/components/ctrl_core/include/ctrl_core/control.h` — replace the two link fields in `control_in_t`:
```c
    bool  link_up;                  /* ZDO-observed join state; STATUS ONLY -- the cooling
                                       dew guard deliberately does not consume it, since a
                                       silently dead coordinator leaves it true forever */
    uint32_t link_last_seen_ms;     /* last inbound ZCL activity or ZDO signal */
```

- [ ] **Step 4: test-runner — full host suite green**

```bash
cmake --build /tmp/vc-tests -j8 && ctest --test-dir /tmp/vc-tests --output-on-failure
```
Expected: `100% tests passed out of 14`.

- [ ] **Step 5: Commit**

```bash
git add -- firmware/components/ctrl_core/include/ctrl_core/alarm.h \
  firmware/components/ctrl_core/alarm.c firmware/components/ctrl_core/control.c \
  firmware/components/ctrl_core/include/ctrl_core/control.h firmware/test_host/test_alarm.c \
&& git commit -m "fix(fw): trigger cooling dew guard on traffic silence instead of ZDO link state" \
  -- firmware/components/ctrl_core/include/ctrl_core/alarm.h \
     firmware/components/ctrl_core/alarm.c firmware/components/ctrl_core/control.c \
     firmware/components/ctrl_core/include/ctrl_core/control.h firmware/test_host/test_alarm.c
```

---

### Task 6: F1 — persist water_running and keep the OnOff attribute in sync

`app_main.c:45` forces `control_task_set_water_running(true)` ("bench default") at every boot, while `zigbee.c:212` builds the OnOff cluster with `.on_off = 0` and nothing ever syncs them. After a power blip the device regulates a live heating loop while HA shows OFF. Persist the last commanded state in its own small NVS key, restore it before the endpoints are built, and write through on every OnOff write.

**Design:** a **separate NVS key**, not a field in the `cfg` blob — a new blob field would change `sizeof(config_t)` and force a `CONFIG_VERSION` bump plus migration for a value that is commanded state, not a tunable. **Boot default when the key is absent: `false`** (device parks at `park_pos` — safe, and consistent with the OnOff attribute default).

**Files:**
- Modify: `firmware/main/config.h`
- Modify: `firmware/main/config.c`
- Modify: `firmware/main/app_main.c:45`
- Modify: `firmware/main/zigbee.c:212,351-354`

**Interfaces:**
- Produces: `bool config_water_running_load(void)` — reads NVS key `"water"` in namespace `"valvectl"`; returns `false` when absent/unreadable.
- Produces: `void config_water_running_save(bool on)` — writes + commits that key; silently no-ops if NVS is unavailable.
- Requires: `config_load()` (which runs `nvs_flash_init()`) must have been called first — `app_main()` already does this at line 40.

- [ ] **Step 1: Declare the API**

In `firmware/main/config.h`, add after the `config_apply_custom` declaration:
```c
/* water_running (commanded regulation enable) is persisted as its OWN small NVS key,
 * deliberately NOT a field in the cfg blob: a new blob field would change
 * sizeof(config_t) and force a CONFIG_VERSION bump + migration for what is commanded
 * state, not a tunable. Absent key -> false (park at park_pos: the safe boot state,
 * and the value the OnOff attribute is built with). */
bool      config_water_running_load(void);
void      config_water_running_save(bool on);
```

- [ ] **Step 2: Implement it**

In `firmware/main/config.c`, add after the `#define NS "valvectl"` line (line 10):
```c
#define KEY_WATER "water"
```
and append at the end of the file:
```c
bool config_water_running_load(void)
{
    nvs_handle_t h;
    if (nvs_open(NS, NVS_READONLY, &h) != ESP_OK) return false;
    uint8_t v = 0;
    esp_err_t e = nvs_get_u8(h, KEY_WATER, &v);
    nvs_close(h);
    if (e != ESP_OK) {
        ESP_LOGI(TAG, "no persisted water_running, defaulting OFF (park)");
        return false;
    }
    return v != 0;
}

void config_water_running_save(bool on)
{
    nvs_handle_t h;
    if (nvs_open(NS, NVS_READWRITE, &h) != ESP_OK) return;
    if (nvs_set_u8(h, KEY_WATER, on ? 1 : 0) == ESP_OK) nvs_commit(h);
    nvs_close(h);
}
```
(`config_factory_reset()` already calls `nvs_erase_all()` on this namespace, which clears the key too — a factory reset therefore boots OFF. Correct.)

- [ ] **Step 3: Restore at boot instead of forcing true**

In `firmware/main/app_main.c`, replace line 45:
```c
    /* Restore the last state HA commanded. Forcing true here (the old "bench default")
     * meant that after any power blip the device regulated a live loop while the OnOff
     * attribute -- and therefore HA -- still read OFF. Must run BEFORE zigbee_start():
     * build_endpoints() seeds the OnOff attribute from control_task_water_running(). */
    control_task_set_water_running(config_water_running_load());
```

- [ ] **Step 4: Seed the OnOff attribute from the restored state and write through on writes**

In `firmware/main/zigbee.c`, replace line 212:
```c
    /* Seeded from the NVS-restored value (app_main sets it before zigbee_start()), so
     * reads and reports of OnOff always agree with what the control task is doing. */
    esp_zb_on_off_cluster_cfg_t oncfg = { .on_off = control_task_water_running() };
```

Replace the OnOff branch of `attr_cb` (lines 351-354):
```c
    if (m->info.cluster == ESP_ZB_ZCL_CLUSTER_ID_ON_OFF) {
        bool on = *(bool*)m->attribute.data.value;
        /* Write-through, with no-op elision: HA re-sending the same state must not
         * erase/write NVS from the Zigbee stack task on every message. */
        if (on != control_task_water_running()) {
            control_task_set_water_running(on);
            config_water_running_save(on);
        }
        return ESP_OK;
    }
```

- [ ] **Step 5: test-runner — host suite still green**

```bash
ctest --test-dir /tmp/vc-tests --output-on-failure
```
Expected: `100% tests passed out of 14`.

- [ ] **Step 6: Commit**

```bash
git add -- firmware/main/config.h firmware/main/config.c firmware/main/app_main.c firmware/main/zigbee.c \
&& git commit -m "fix(fw): persist water_running in NVS and seed the OnOff attribute from it" \
  -- firmware/main/config.h firmware/main/config.c firmware/main/app_main.c firmware/main/zigbee.c
```

---

### Task 7: F2 — publish the ZCL invalid sentinel for faulted probes

`zigbee.c:506` and `:557` publish `sensors_get(id).value_c` ignoring `.fault`, so a dead probe's last-good value (or BSS `0.0`) is reported forever as a live measurement. Publish `0x8000` — the ZCL invalid sentinel for both Temperature Measurement `MeasuredValue` and Thermostat `LocalTemperature` — and make the z2m converter surface it as `null`.

**Files:**
- Modify: `firmware/main/zigbee.c:498-511,554-561`
- Modify: `z2m/valvectl.mjs:163` + new converter

- [ ] **Step 1: Add the sentinel helper in zigbee.c**

Insert immediately above `void zigbee_report_temps(void)` (line 498):
```c
/* ZCL "invalid" sentinel for the int16 temperature attributes -- Temperature
 * Measurement MeasuredValue and Thermostat LocalTemperature both define 0x8000
 * (== -32768) as "value not available". add_temp_ep() already seeds the cluster
 * with it, so the stack accepts it. */
#define ZCL_TEMP_INVALID ((int16_t)0x8000)

/* A latched-faulted probe holds its last-good value forever -- or 0.0 from BSS if it
 * never produced one. Publishing that as a live measurement is a lie the coordinator
 * cannot detect: HA charts a plausible frozen temperature and no automation notices.
 * Publish the sentinel instead. */
static int16_t temp_centi(sensor_id_t id)
{
    sensor_reading_t r = sensors_get(id);
    if (r.fault) return ZCL_TEMP_INVALID;
    return (int16_t)(r.value_c * 100.0f);
}
```

- [ ] **Step 2: Use it in both publish paths**

In `zigbee_report_temps()`, replace line 506:
```c
        int16_t v = temp_centi(map[i].id);
```

In `set_local_temperature()`, replace line 557:
```c
    int16_t lt = temp_centi(SENS_SUPPLY);
```

- [ ] **Step 3: Make the z2m converter surface the sentinel as null**

In `z2m/valvectl.mjs`, insert above `const fzWaterRunning = {` (line 128):
```js
// The generic fz.temperature has no guard for the ZCL invalid sentinel and would
// publish -327.68 °C as a real reading. The firmware sends 0x8000 (-32768) for any
// probe whose fault is latched (temp_centi() in firmware/main/zigbee.c).
const fzTemperature = {
    cluster: 'msTemperatureMeasurement', type: ['attributeReport', 'readResponse'],
    convert: (model, msg, publish, options, meta) => {
        if (msg.data.measuredValue === undefined) return;
        // multiEndpoint postfix built explicitly rather than via postfixWithEndpointName(),
        // whose signature has changed across zigbee-herdsman-converters versions. The
        // endpoint map below names endpoints '2'..'6' identically to their IDs, so this
        // produces exactly the `temperature_<ep>` properties the exposes declare.
        const property = `temperature_${msg.endpoint.ID}`;
        if (msg.data.measuredValue === -32768) return {[property]: null};
        return {[property]: Math.round(msg.data.measuredValue) / 100};
    },
};
```

Replace the `fromZigbee` line (line 163):
```js
    fromZigbee: [fzWaterRunning, fzTemperature, fz.thermostat, fzRunningMode, fzAnalogOutput, fzCustom],
```

`fz.thermostat` handles `localTemp` and current upstream versions already drop values below −273.15 °C, and `local_temperature` is not in `exposes` anyway — so no change is needed there. Confirm at deploy time against the installed converter version (Unresolved Q6).

- [ ] **Step 4: test-runner — host suite still green**

```bash
ctest --test-dir /tmp/vc-tests --output-on-failure
```
Expected: `100% tests passed out of 14`.

- [ ] **Step 5: Commit**

```bash
git add -- firmware/main/zigbee.c z2m/valvectl.mjs \
&& git commit -m "fix(fw): publish ZCL invalid sentinel 0x8000 for faulted temperature probes" \
  -- firmware/main/zigbee.c z2m/valvectl.mjs
```

---

### Task 8: F3 + F16 + F17a — sweep watchdog, staleness fault, coherent snapshot

`sensors_hw.c:90` `sweep_task` is not registered with the task WDT and `last_ok_ms` (written at `:77`) is never checked, so a wedged sweep leaves every reading frozen with `fault == false` and the control loop keeps integrating on stale data forever. `sensors_fill_faults()` at `:131` also takes `g_lock` five times, so the control loop can get a torn snapshot. Fix all three in one locked pass, and stop discarding the `esp_task_wdt_add()` return in the other two tasks.

**Files:**
- Modify: `firmware/main/sensors_hw.c:1-10,22,90-92,131-138`
- Modify: `firmware/main/control_task.c:34`
- Modify: `firmware/main/valve_hw.c:57`

- [ ] **Step 1: Register the sweep task with the watchdog**

In `firmware/main/sensors_hw.c`, add after `#include "esp_log.h"` (line 7):
```c
#include "esp_task_wdt.h"
```

Replace lines 90-92:
```c
static void sweep_task(void *arg)
{
    /* Subscribed to the task WDT like the control and valve tasks: an RMT/1-Wire wedge
     * here used to be invisible (readings simply froze) rather than causing the reset +
     * rollback the watchdog exists to produce. One iteration is ~10 s (750 ms convert +
     * 9.25 s delay), well inside the 30 s budget. */
    ESP_ERROR_CHECK(esp_task_wdt_add(NULL));
    for (;;) {
        esp_task_wdt_reset();
```

- [ ] **Step 2: Add the staleness constant**

In `firmware/main/sensors_hw.c`, add after `#define EMA_TAU_S 40.0f` (line 25):
```c
/* Belt-and-braces for a sweep that stops producing readings without failing them
 * (task starved, RMT wedged, sweep_task deleted). Independent of the latch state:
 * a reading whose last good sweep is older than this is reported faulted, so control
 * degrades to park instead of silently integrating frozen data. 3 sweep periods plus
 * 5 s of slack. */
#define SENSOR_STALE_MS (3u * SWEEP_PERIOD_MS + 5000u)   /* 35 s */
```

- [ ] **Step 3: One locked pass, with the staleness check folded in**

Replace `sensors_fill_faults()` (lines 131-138) entirely:
```c
/* One locked pass. Taking g_lock five times (once per sensors_get) let the sweep task
 * interleave and hand the control loop a mix of pre- and post-sweep fault state. */
void sensors_fill_faults(sensor_faults_t *o)
{
    uint32_t now = (uint32_t)(esp_timer_get_time() / 1000);
    bool f[SENS_COUNT];

    xSemaphoreTake(g_lock, portMAX_DELAY);
    for (int i = 0; i < SENS_COUNT; ++i) {
        /* last_ok_ms == 0 means "never read a good value"; sensors_start() already boots
         * that sensor as latched-faulted, so no staleness test is needed (and applying
         * one would be wrong -- now - 0 is just uptime). */
        bool stale = (g_read[i].last_ok_ms != 0) &&
                     ((now - g_read[i].last_ok_ms) > SENSOR_STALE_MS);
        f[i] = g_read[i].fault || stale;
    }
    xSemaphoreGive(g_lock);

    o->supply = f[SENS_SUPPLY];
    o->ret    = f[SENS_RETURN];
    o->source = f[SENS_SOURCE];
    o->hx_a   = f[SENS_HX_A];
    o->hx_b   = f[SENS_HX_B];
}
```

- [ ] **Step 4: Stop discarding the other two `esp_task_wdt_add()` returns (F17a)**

In `firmware/main/control_task.c`, the first line of `control_loop()` — `    esp_task_wdt_add(NULL);` — becomes:
```c
    ESP_ERROR_CHECK(esp_task_wdt_add(NULL));
```
(`esp_err.h` is reachable via the existing `esp_task_wdt.h` include.)

In `firmware/main/valve_hw.c`, the first line of `valve_task()` — `    esp_task_wdt_add(NULL);` — becomes:
```c
    ESP_ERROR_CHECK(esp_task_wdt_add(NULL));
```

- [ ] **Step 5: test-runner — host suite still green**

```bash
ctest --test-dir /tmp/vc-tests --output-on-failure
```
Expected: `100% tests passed out of 14`.

- [ ] **Step 6: Commit**

```bash
git add -- firmware/main/sensors_hw.c firmware/main/control_task.c firmware/main/valve_hw.c \
&& git commit -m "fix(fw): watchdog the sensor sweep, fault stale readings, snapshot faults under one lock" \
  -- firmware/main/sensors_hw.c firmware/main/control_task.c firmware/main/valve_hw.c
```

---

### Task 9: F6 + F9 — echo clamped thermostat setpoints back, elide no-op saves

`zigbee.c:358-365` clamps the heating/cooling setpoint into `g_config` and saves, but never echoes the clamped value into the ZCL attribute store — unlike every custom-cluster tunable at `:396-442`. The stack has already latched the raw write, so a 40 °C write leaves HA reading a setpoint the device will never honour. The same branches also call `config_save()` unconditionally, so every HA re-send erases/writes NVS from the Zigbee stack task.

**Files:**
- Modify: `firmware/main/zigbee.c:355-367`

- [ ] **Step 1: Implement both fixes**

Replace the thermostat branch of `attr_cb` (lines 355-367):
```c
    if (m->info.cluster == ESP_ZB_ZCL_CLUSTER_ID_THERMOSTAT) {
        if (m->attribute.id == ESP_ZB_ZCL_ATTR_THERMOSTAT_SYSTEM_MODE_ID)
            return ESP_OK;   /* accepted-but-ignored: mode is auto-detected */
        /* Setpoints are clamped to the same 17..35 C band control_task.c re-clamps with.
         * Two things follow, both previously missing:
         *  - echo the clamped value back UNCONDITIONALLY: the stack already latched the
         *    raw write into the attribute store, so without this a 40 C write leaves the
         *    store at 4000 and HA reads back a setpoint the device will never honour.
         *    Safe to call from here -- this runs in the stack task, same as the
         *    ATTR_RESYNC self-clear below;
         *  - only config_save() when g_config actually changed, so HA re-sending the
         *    same setpoint (or one that clamps back to the current value) does not
         *    erase/write NVS from the stack task on every message. */
        if (m->attribute.id == ESP_ZB_ZCL_ATTR_THERMOSTAT_OCCUPIED_HEATING_SETPOINT_ID) {
            float c = ctrl_clampf(*(int16_t*)m->attribute.data.value / 100.0f, 17.0f, 35.0f);
            if (c != g_config.heat_setpoint) { g_config.heat_setpoint = c; config_save(); }
            int16_t echo = (int16_t)(c * 100.0f + 0.5f);   /* c >= 17, so +0.5 rounds */
            esp_zb_zcl_set_attribute_val(EP_MAIN, ESP_ZB_ZCL_CLUSTER_ID_THERMOSTAT,
                ESP_ZB_ZCL_CLUSTER_SERVER_ROLE,
                ESP_ZB_ZCL_ATTR_THERMOSTAT_OCCUPIED_HEATING_SETPOINT_ID, &echo, false);
        }
        if (m->attribute.id == ESP_ZB_ZCL_ATTR_THERMOSTAT_OCCUPIED_COOLING_SETPOINT_ID) {
            float c = ctrl_clampf(*(int16_t*)m->attribute.data.value / 100.0f, 17.0f, 35.0f);
            if (c != g_config.cool_setpoint) { g_config.cool_setpoint = c; config_save(); }
            int16_t echo = (int16_t)(c * 100.0f + 0.5f);
            esp_zb_zcl_set_attribute_val(EP_MAIN, ESP_ZB_ZCL_CLUSTER_ID_THERMOSTAT,
                ESP_ZB_ZCL_CLUSTER_SERVER_ROLE,
                ESP_ZB_ZCL_ATTR_THERMOSTAT_OCCUPIED_COOLING_SETPOINT_ID, &echo, false);
        }
        return ESP_OK;
    }
```

- [ ] **Step 2: test-runner — host suite still green**

```bash
ctest --test-dir /tmp/vc-tests --output-on-failure
```
Expected: `100% tests passed out of 14`.

- [ ] **Step 3: Commit**

```bash
git add -- firmware/main/zigbee.c \
&& git commit -m "fix(fw): echo clamped thermostat setpoints back to the attribute store, elide no-op saves" \
  -- firmware/main/zigbee.c
```

---

### Task 10: F11 — latch travel_time_s alongside the direction swap

`valve_hw.c:67` recomputes the resync stall time live from `g_config.travel_time_s` while `s_swap_latched` (`:88`) is frozen. A mid-stroke `travel_time_s` write collapses the stall time and corrupts the position estimator, which reads the same live value at `:90`. Latch both together.

**Files:**
- Modify: `firmware/main/valve_hw.c:27-30,67,86-90,101`

- [ ] **Step 1: Add the latch**

In `firmware/main/valve_hw.c`, replace lines 27-30 (the `s_swap_latched` comment and declaration):
```c
/* Latched copies of the motion-affecting config, refreshed only while idle (see
 * valve_task), so a runtime config change never flips the open/close mapping nor
 * rescales the stall/position math mid-stroke or mid-resync. */
static bool              s_swap_latched = false;
static uint32_t          s_travel_latched_s = 0;
```

- [ ] **Step 2: Read the latch in the resync stall math**

Inside the `if (s_rs == RS_DRIVING)` branch of `valve_task()`, replace
```c
            uint32_t stall_ms = (uint32_t)(g_config.travel_time_s * 1000.0f * RESYNC_STALL_MULT);
```
with
```c
            uint32_t stall_ms = (uint32_t)(s_travel_latched_s * 1000.0f * RESYNC_STALL_MULT);
```

- [ ] **Step 3: Refresh both latches at the same idle point, and feed the estimator from the latch**

Replace the idle-latch comment, its `if`, and the `pos_est_update` call that follows it —
```c
        /* Idle (not driving, not mid-resync): safe point to pick up a direction_swap change
         * for the *next* motion. While actually moving, the latch stays frozen. */
        if (applied == VALVE_STOP && s_rs == RS_IDLE) s_swap_latched = g_config.direction_swap;

        pos_est_update(&s_pos, travel_sign_of(applied), TICK_MS, (float)g_config.travel_time_s);
```
— with:
```c
        /* Idle (not driving, not mid-resync): the only safe point to pick up config
         * changes for the *next* motion. While actually moving, both latches stay
         * frozen -- a travel_time_s write mid-stroke would otherwise rescale the
         * position estimator's %-per-tick under it. */
        if (applied == VALVE_STOP && s_rs == RS_IDLE) {
            s_swap_latched     = g_config.direction_swap;
            s_travel_latched_s = g_config.travel_time_s;
        }

        pos_est_update(&s_pos, travel_sign_of(applied), TICK_MS, (float)s_travel_latched_s);
```

- [ ] **Step 4: Seed the latch at boot**

In `valve_start()`, replace
```c
    s_swap_latched = g_config.direction_swap;              /* initial latch at boot */
```
with
```c
    s_swap_latched     = g_config.direction_swap;          /* initial latch at boot */
    s_travel_latched_s = g_config.travel_time_s;
```

- [ ] **Step 5: test-runner — host suite still green**

```bash
ctest --test-dir /tmp/vc-tests --output-on-failure
```
Expected: `100% tests passed out of 14`.

- [ ] **Step 6: Commit**

```bash
git add -- firmware/main/valve_hw.c \
&& git commit -m "fix(fw): latch travel_time_s with the direction swap so mid-stroke writes can't corrupt position" \
  -- firmware/main/valve_hw.c
```

---

### Task 11: F10 — fail loudly on a short first OTA payload block

`ota.c:180` silently returns `ESP_OK` when the first payload block is `<= OTA_SUBELEMENT_HDR_LEN`, with a comment claiming "wait for more" — but there is no accumulation buffer, so those bytes are simply discarded and the image is corrupted with no diagnostic. Unreachable at `max_data_size = 64` (`zigbee.c:252`), but load-bearing.

**Files:**
- Modify: `firmware/main/ota.c:179-184`

- [ ] **Step 1: Implement**

In `firmware/main/ota.c`, replace lines 179-184:
```c
        if (!s_dl_trimmed) {
            /* The 6-byte sub-element header always arrives whole in the first block:
             * max_data_size is 64 (zigbee.c), ten times this header. A shorter first
             * block means the server framed the image differently than assumed, and
             * there is NO accumulation buffer here to re-assemble it -- the old code
             * returned ESP_OK and silently dropped image bytes, producing a corrupt
             * flash write with no diagnostic. Fail visibly instead. */
            if (len <= OTA_SUBELEMENT_HDR_LEN) {
                ESP_LOGE(TAG, "first OTA payload block is %u bytes, <= the %u-byte "
                              "sub-element header; cannot trim without buffering",
                         (unsigned)len, (unsigned)OTA_SUBELEMENT_HDR_LEN);
                download_abort("short first payload block");
                return ESP_FAIL;
            }
            data += OTA_SUBELEMENT_HDR_LEN;
            len  -= OTA_SUBELEMENT_HDR_LEN;
            s_dl_trimmed = true;
        }
```

- [ ] **Step 2: test-runner — host suite still green**

```bash
ctest --test-dir /tmp/vc-tests --output-on-failure
```
Expected: `100% tests passed out of 14`.

- [ ] **Step 3: Commit**

```bash
git add -- firmware/main/ota.c \
&& git commit -m "fix(fw): abort the OTA transfer on a short first payload block instead of dropping bytes" \
  -- firmware/main/ota.c
```

---

### Task 12: F14 + F17b — nits (stale TODO, OTA size diagnostic)

No test steps: neither change is behavioural. VERIFY is "suite still green + grep clean".

**Correction to the review finding for F17b:** the finding proposed warning when `s_dl_written != s_dl_total`. That would fire on **every successful OTA**. `ota_header.image_size` is the *total .ota file size* — `tools/make_ota.py` builds it as `HEADER_LENGTH (56) + 6 + len(image)` — while `s_dl_written` counts app-binary bytes only, so a healthy transfer differs by exactly 62. Warn only on genuinely impossible accounting, and log the expected delta.

**Interlock note (F17c), no code change:** `interlock.c:15` `both_error_count` is unreachable given the current callers. It is **deliberately retained** — a zero-cost safety net against a future caller asserting both directions, which on this hardware means shorting both triacs.

**Files:**
- Modify: `firmware/main/zigbee.c:75`
- Modify: `firmware/main/ota.c:132,195-198`

- [ ] **Step 1: Delete the stale TODO (F14)**

`valve_travel_since_resync()` has existed at `valve_hw.c:126` since 1.1.x and is used at `zigbee.c:547`. In `firmware/main/zigbee.c`, replace line 75:
```c
static float    s_attr_travel_since;  /* mirrors valve_travel_since_resync(); pushed by zigbee_push_status() */
```

- [ ] **Step 2: Add the OTA size diagnostic (F17b)**

In `firmware/main/ota.c`, add below `#define OTA_SUBELEMENT_HDR_LEN 6` (line 132):
```c
#define OTA_FILE_HDR_LEN       56   /* ZCL OTA file header the stack strips before us */
```

Replace the `STATUS_CHECK` case (lines 195-198):
```c
    case ESP_ZB_ZCL_OTA_UPGRADE_STATUS_CHECK:
        /* ota_header.image_size is the TOTAL advertised .ota file size (tools/make_ota.py
         * builds it as OTA_FILE_HDR_LEN + OTA_SUBELEMENT_HDR_LEN + the app binary), while
         * s_dl_written counts app-binary bytes only -- so a healthy transfer differs by
         * exactly 62 and must NOT warn. What is never legitimate is writing zero bytes,
         * or more bytes than the whole file: both mean the trim/accounting is wrong. */
        if (s_dl_written == 0 || s_dl_written > s_dl_total)
            ESP_LOGW(TAG, "OTA accounting looks wrong: wrote %lu app bytes for a %lu-byte file",
                     (unsigned long)s_dl_written, (unsigned long)s_dl_total);
        ESP_LOGI(TAG, "OTA image received: %lu app bytes written (advertised file size %lu, "
                      "expected difference %u)",
                 (unsigned long)s_dl_written, (unsigned long)s_dl_total,
                 (unsigned)(OTA_FILE_HDR_LEN + OTA_SUBELEMENT_HDR_LEN));
        return ESP_OK;
```

- [ ] **Step 3: VERIFY — grep clean and suite green**

```bash
grep -rn "TODO" firmware/main/ firmware/components/   # expect: no hits
ctest --test-dir /tmp/vc-tests --output-on-failure
```
Expected: no TODO hits in `firmware/main/` or `firmware/components/`; `100% tests passed out of 14`.

- [ ] **Step 4: Commit**

```bash
git add -- firmware/main/zigbee.c firmware/main/ota.c \
&& git commit -m "docs(fw): drop stale travel-since TODO, correct the OTA size diagnostic" \
  -- firmware/main/zigbee.c firmware/main/ota.c
```

---

### Task 13: Release 1.3.0

**Files:**
- Modify: `firmware/version.txt`
- Modify: `firmware/README.md`

- [ ] **Step 1: Bump the version**

`firmware/version.txt` — replace the entire contents with:
```
1.3.0
```

- [ ] **Step 2: Add the release notes to the README**

In `firmware/README.md`, immediately **above** the `## Prerequisites` heading, insert:
```markdown
## 1.3.0 — review-findings release

Safety and correctness fixes from the 2026-07-31 firmware review:

- **water_running now survives a reboot.** Persisted in its own NVS key (`valvectl/water`,
  outside the cfg blob, so no `CONFIG_VERSION` bump) and used to seed the OnOff attribute
  at endpoint build. Previously every boot forced regulation ON while HA read OFF. Absent
  key ⇒ OFF (parks at `park_pos`). A factory reset therefore boots OFF.
- **Faulted probes publish the ZCL invalid sentinel `0x8000`** instead of a frozen
  last-good value, on both Temperature Measurement `MeasuredValue` and Thermostat
  `LocalTemperature`. `z2m/valvectl.mjs` maps it to `null`.
- **The sensor sweep is watchdogged**, and any reading older than 35 s (3 sweep periods
  + slack) is reported faulted regardless of latch state — a wedged sweep now degrades
  control to park instead of integrating frozen data. `sensors_fill_faults()` takes one
  coherent locked snapshot.
- **OTA validation gate moved outside the watchdog window:** 12 control cycles (~110 s)
  instead of 3 (~20 s), extracted to `ctrl_core/ota_gate.c` and host-tested.
- **Fault-streak decay requires 3 consecutive good reads** (break-even 25 % failure rate,
  was 33 %) — a probe failing a third of its sweeps now latches.
- **Thermostat setpoint writes echo the clamped value back** to the attribute store, and
  only write NVS when the value actually changed.
- **Cooling dew guard triggers on 30 min of traffic silence** rather than a ZDO link-down
  signal, which a silently dead coordinator never sends.
- **Supply freeze alarm is held while the supply probe is faulted** (no false latch on a
  BSS-zero reading, no false clear on a frozen in-band one).
- `travel_time_s` is latched with `direction_swap`, so a mid-stroke write cannot corrupt
  the position estimate; a short first OTA payload block now aborts loudly.
```

- [ ] **Step 3: VERIFY — full host suite green**

```bash
rm -rf /tmp/vc-tests && cmake -S firmware/test_host -B /tmp/vc-tests \
  -DFETCHCONTENT_SOURCE_DIR_UNITY=/Users/kleist/Sites/ValveController/firmware/test_host/build-121a/_deps/unity-src \
&& cmake --build /tmp/vc-tests -j8 \
&& ctest --test-dir /tmp/vc-tests --output-on-failure
```
Expected: `100% tests passed out of 14`.

- [ ] **Step 4: VERIFY — clean full target build**

```bash
source ~/esp/esp-idf/export.sh && cd firmware && idf.py fullclean && idf.py build
```
Expected: build succeeds, no warnings introduced by this plan's files, and the summary
reports project version `1.3.0`.

- [ ] **Step 5: Build the OTA artifact**

`--out` takes a **DIRECTORY**, not a file path; the script names the file
`valvecontroller-<version>.ota` itself.
```bash
python3 tools/make_ota.py --out /tmp/vc-ota
```
Expected output includes `version : 1.3.0 -> 0x01030000` and
`wrote : /tmp/vc-ota/valvecontroller-1.3.0.ota`.

- [ ] **Step 6: Commit**

```bash
git add -- firmware/version.txt firmware/README.md \
&& git commit -m "docs(fw): release 1.3.0 — review-findings fixes" \
  -- firmware/version.txt firmware/README.md
```

- [ ] **Step 7: Hand off deployment (NOT part of this plan)**

Report to the owner, do not perform: USB flash or OTA staging of
`valvecontroller-1.3.0.ota`, adding the Z2M local OTA index entry (`fileVersion`
`0x01030000`, `imageType 0x0001`, `manufacturerCode 0x1234`, `modelId "HydroMix"`), and
copying `z2m/valvectl.mjs` to `/config/zigbee2mqtt/` on HAOS + restarting Z2M. The
converter change in Task 7 is required for the `0x8000` sentinel to render as
unavailable rather than −327.68 °C.

---

## Unresolved questions

1. F1 boot default when NVS key absent: false (park) chosen — OK? Alternative: true matches old behavior but recreates the mismatch.
2. F5 decay policy: 3-consecutive-goods (break-even 25 %) chosen over windowed failure-rate counter (better diagnostics, more state + new attr). OK?
3. F7 passive liveness needs periodic inbound traffic — is Z2M availability enabled for this device? If not, guard may false-trigger cooling setpoint raise to 21 °C after quiet periods; enable availability or lengthen window?
   *(Added while reading code: plain attribute READS are answered inside the stack and never reach `action_handler`, so the liveness signal depends on writes / OTA / reporting-config traffic specifically. Also note the failure mode is the safe direction — less cooling — so a false trigger is a comfort issue, not a damage one.)*
4. Release: single 1.3.0 with everything, or split safety-critical (F1-F4) into a fast 1.2.2?
5. Z2M converter exposes no climate/setpoint entities (tz handlers exist, no exposes) — add them in this release?
   *(Confirmed while reading `z2m/valvectl.mjs`: `tz.thermostat_occupied_heating_setpoint` / `_cooling_setpoint` are wired into `toZigbee` at line 164-165, but there is no `e.climate()` in `exposes`, so both setpoints are unreachable from HA today.)*
6. **(new) `fz.thermostat` localTemp sentinel guard:** current upstream `zigbee-herdsman-converters` drops `localTemp` values below −273.15 °C, which would filter our `0x8000`. Unverified against the version actually installed on this HAOS. If that guard is absent there, `local_temperature` will publish −327.68 °C — harmless today (not exposed), but it becomes visible the moment Q5 is answered "yes". Verify at deploy time?
7. **(new) `ota_header.image_size` semantics as delivered by ZBOSS:** Task 12 assumes it is the *total* .ota file size (56-byte header + 6-byte sub-element + binary), matching what `tools/make_ota.py` writes. The 1.2.1 OTA performed today logged `OTA image received: <written> bytes written (header size <total>)` — can the owner check that line in the device log to confirm the 62-byte difference? If ZBOSS instead reports the post-header size, the new diagnostic is still correct (it only warns on impossible values) but the logged "expected difference" is misleading.
8. **(new) Task 4-before-Task 5 ordering:** this inverts the requested "ctrl_core first" grouping, because shipping the guard-semantics change before the liveness plumbing would let a long-joined device spuriously raise its cooling setpoint. Confirm the reordering is acceptable.
9. **(new) 16 stray `firmware/test_host/build-*` directories** are untracked in the repo and one of them (`build-121a`) is now load-bearing for this plan's `FETCHCONTENT_SOURCE_DIR_UNITY` override. Delete them and vendor Unity properly (or add a `.gitignore` entry) as a follow-up?

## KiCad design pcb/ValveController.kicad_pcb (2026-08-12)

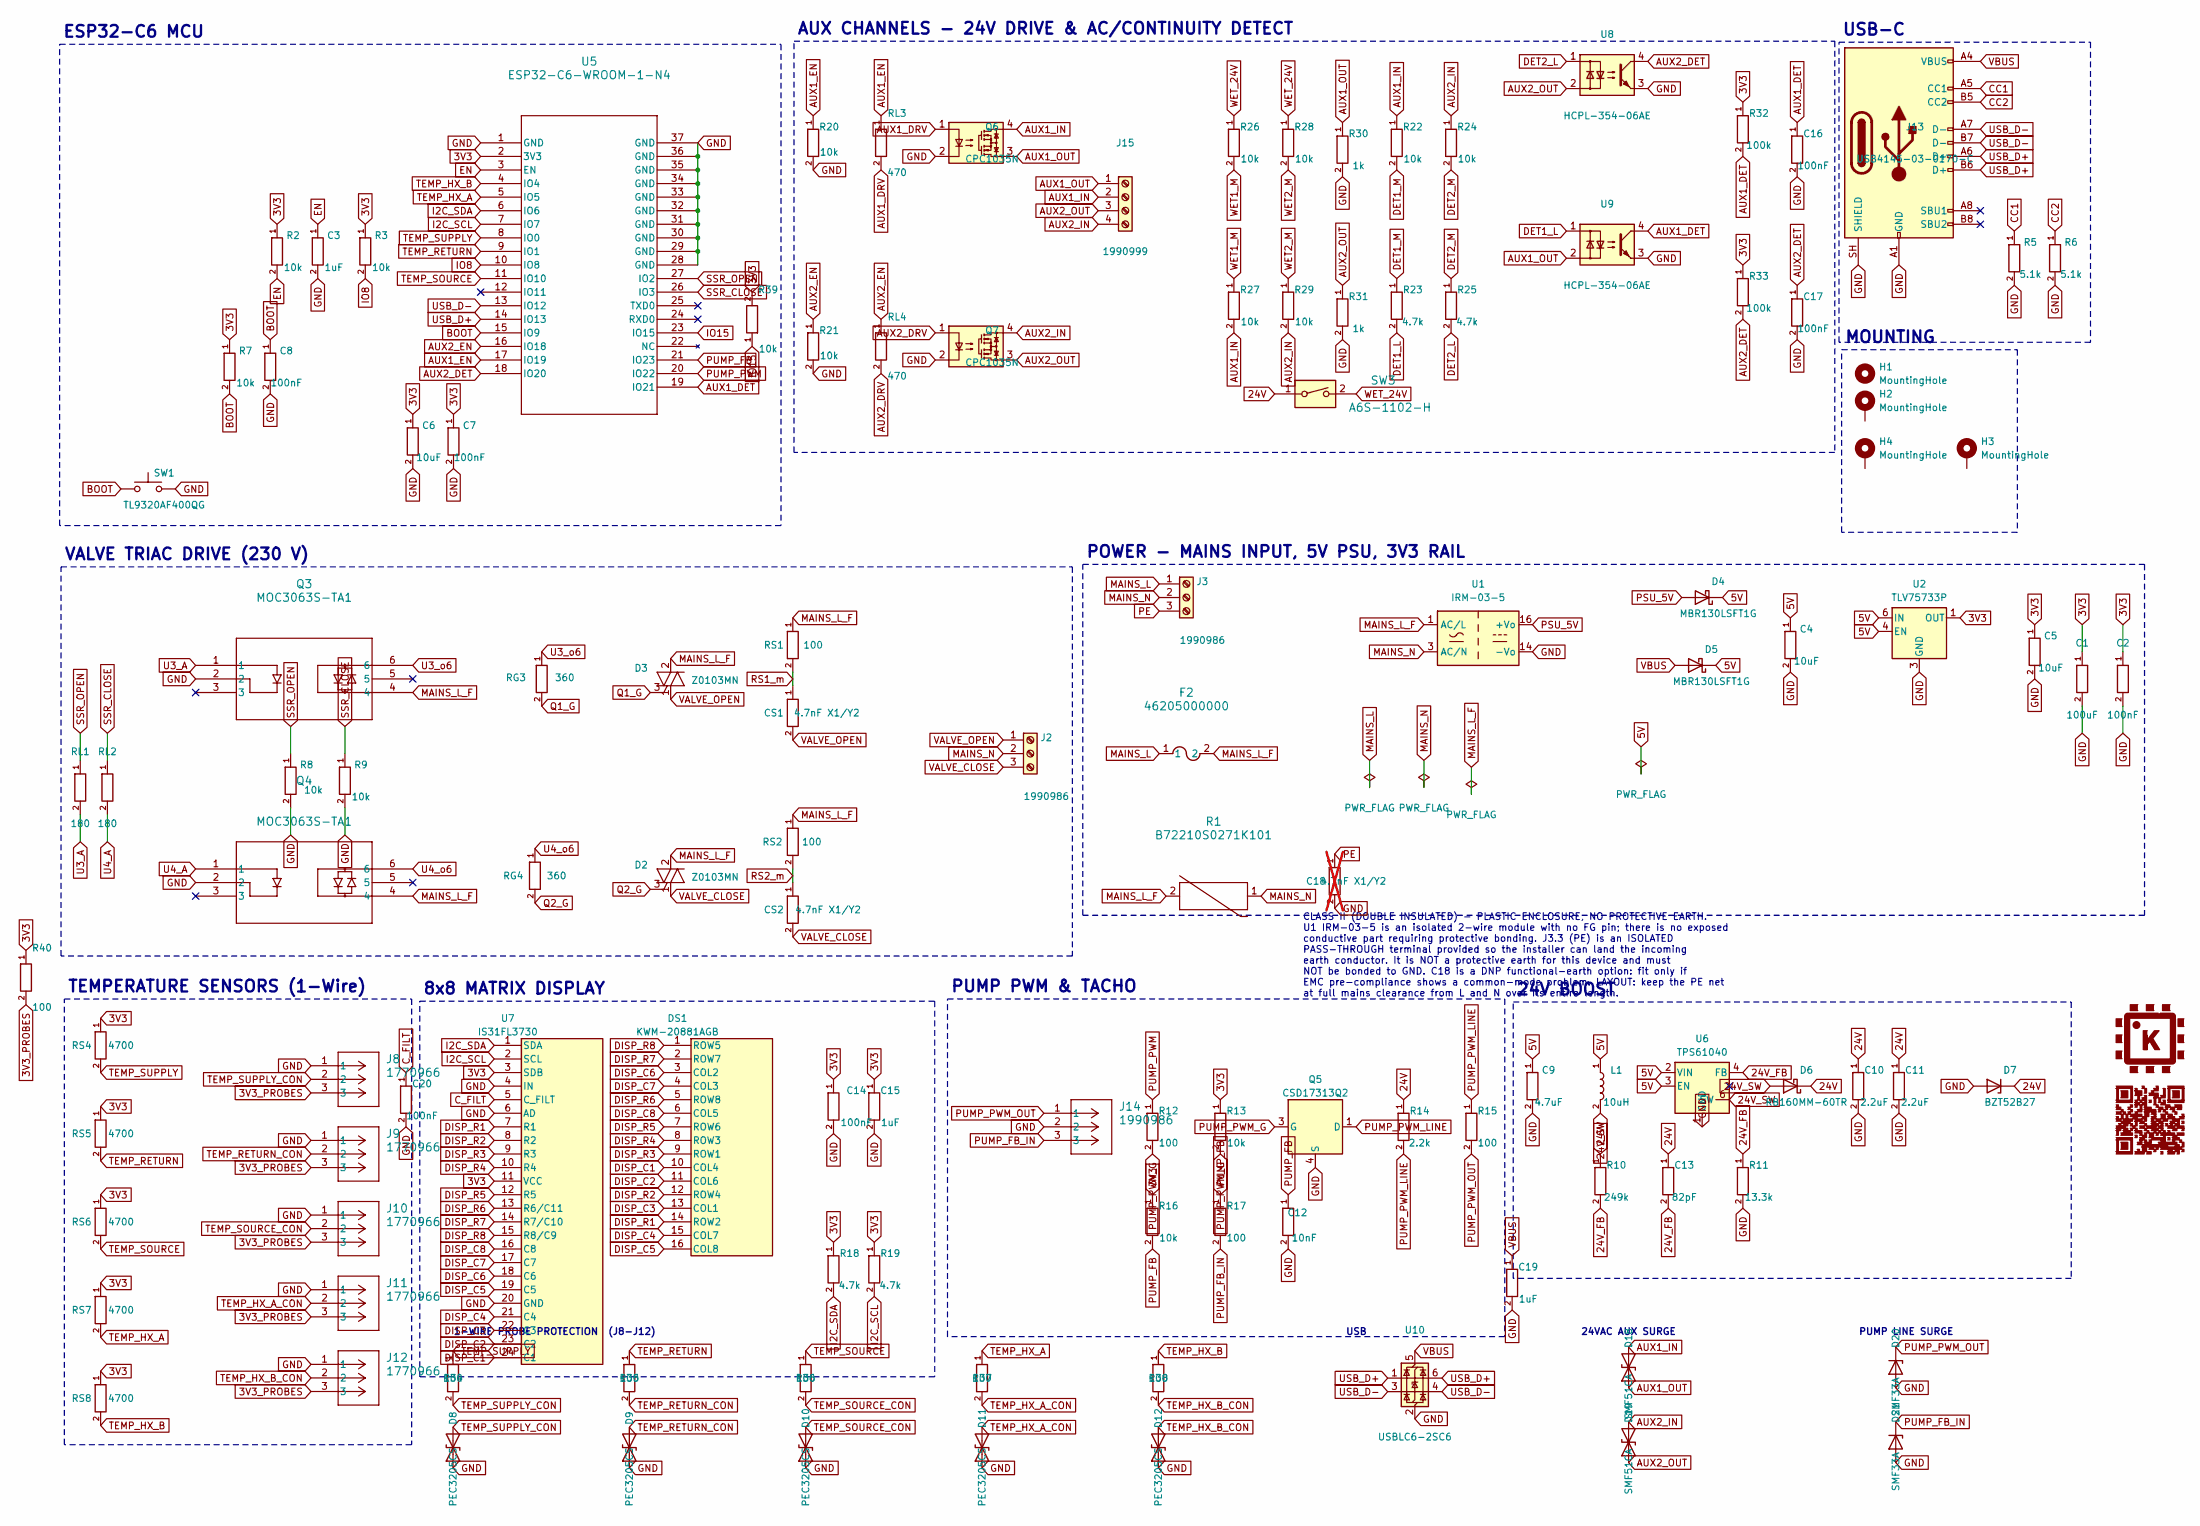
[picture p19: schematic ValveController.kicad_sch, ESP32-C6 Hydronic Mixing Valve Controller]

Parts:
C1: 100uF; C_1210_3225Metric; MPN CL32A107MQVNNNE
C2, C7, C8, C14, C16, C17, C20: 100nF; C_0402_1005Metric; MPN CL05B104KO5NNNC
C3, C15, C19: 1uF; C_0402_1005Metric; MPN CL05A105KP5NNNC
C4, C5, C6: 10uF; C_0805_2012Metric; MPN C0805C106K3PACTU
C9: 4.7uF; C_0805_2012Metric; MPN GRM21BR71C475KE51K
C10, C11: 2.2uF; C_1206_3216Metric; MPN GCM31CR71H225KA55L
C12: 10nF; C_0402_1005Metric; MPN C0402C103K5RECAUTO
C13: 82pF; C_0402_1005Metric; MPN GRM1555C1H820JA01D
C18: 4.7nF X1/Y2; C_Rect_L13.0mm_W5.0mm_P10.00mm_FKS3_FKP3_MKS4; MPN R413F147050T1K; not fitted
CS1, CS2: 4.7nF X1/Y2; C_Rect_L13.0mm_W5.0mm_P10.00mm_FKS3_FKP3_MKS4; MPN R413F147050T1K
D2, D3: Z0103MN; SOT-223; MPN Z0103MN 5AA4
D4, D5: MBR130LSFT1G; D_SOD-123F; MPN MBR130LSFT1G
D6: RB160MM-60TR; D_SOD-123F; MPN RB160MM-60TR
D7: BZT52B27; D_SOD-123F; MPN BZT52B27
D8, D9, D10, D11, D12: PEC3205CS; D_SOD-323F; MPN PEC3205CS_R1_00701
D18, D19: SMF51CA; D_SOD-123F; MPN SMF51CA
D20, D21: SMF33A; D_SOD-123F; MPN SMF33A
DS1: KWM-20881AGB; LED_Matrix_8x8_20mm; MPN KWM-20881AGB
F2: 46205000000; Fuse_Littelfuse-NANO2-462; MPN 46205000000
G1: KleistLabs_Logo_8mm_Copper
G2: QR_HydroMix_SilkOnDark; QR_HydroMix_250um_SilkOnDark
H1, H2, H3, H4: MountingHole; MountingHole_3.2mm_M3_ISO7380
J2, J3, J14: 1990986; TerminalBlock_Phoenix_SPT-2,5-3-H-5.0_1x03_P5.00mm_Horizont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; MPN 1990986
J8, J9, J10, J11, J12: 1770966; TerminalBlock_Phoenix_PTSM-0,5-3-2.5-V-THR_1x03_P2.50mm_Ver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; MPN 1770966
J13: USB4145-03-0170-C; USB_C_Receptacle_GCT_USB4145-03-0170-C_Vertical_SMT; MPN USB4145-03-0170-C
J15: 1990999; TerminalBlock_Phoenix_SPT-2,5-4-H-5.0_1x04_P5.00mm_Horizont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; MPN 1990999
L1: 10uH; L_Taiyo-Yuden_NR-40xx; MPN LSXND4040TKL100MDG
Q3, Q4: MOC3063S-TA1; MOC306XS_LTO-L; MPN MOC3063S-TA1
Q5: CSD17313Q2; MPN CSD17313Q2
Q6, Q7: CPC1035N; SOP-4_3.8x4.1mm_P2.54mm; MPN CPC1035NTR
R1: B72210S0271K101; RV_Disc_D12mm_W5.4mm_P7.5mm; MPN B72210S0271K101
R2, R3, R7, R8, R9, R13, R16, R20, R21, R22, R24, R26, R27, R28, R29, R39: 10k; R_0402_1005Metric; MPN AC0402FR-0710KL
R5, R6: 5.1k; R_0402_1005Metric; MPN RC0402FR-075K1L
R10: 249k; R_0402_1005Metric; MPN RC0402FR-07249KL
R11: 13.3k; R_0402_1005Metric; MPN RC0402FR-0713K3L
R12, R34, R35, R36, R37, R38: 100; R_0402_1005Metric; MPN RC0402FR-07100RL
R14: 2.2k; R_1206_3216Metric; MPN ERJ-P08J222V
R15, R17, R40: 100; R_1206_3216Metric; MPN ERJ-P08J101V
R18, R19, R23, R25: 4.7k; R_0402_1005Metric; MPN RC0402FR-074K7L
R30, R31: 1k; R_0402_1005Metric; MPN user stock (1k 0402)
R32, R33: 100k; R_0402_1005Metric; MPN RC0402FR-07100KL
RG3, RG4: 360; R_0603_1608Metric; MPN RC0603FR-07360RL
RL1, RL2: 180; R_0402_1005Metric; MPN RC0402FR-07180RL
RL3, RL4: 470; R_0402_1005Metric; MPN RC0402FR-07470RL
RS1, RS2: 100; R_1206_3216Metric; MPN ERJ-P08J101V
RS4, RS5, RS6, RS7, RS8: 4700; R_0402_1005Metric; MPN RC0402FR-074K7L
SW1: TL9320AF400QG; SW_SPST_TL9320; MPN TL9320AF400QG
SW3: A6S-1102-H; SW_DIP_SPSTx01_Slide_Omron_A6S-110x_W8.9mm_P2.54mm; MPN A6S-1102-H
U1: IRM-03-5; Converter_ACDC_MeanWell_IRM-03-xx_THT; MPN IRM-03-5
U2: TLV75733P; WSON-6-1EP_2x2mm_P0.65mm_EP1x1.6mm_ThermalVias; MPN TLV75733PDRVR
U5: ESP32-C6-WROOM-1-N4; MOD28_ESP32-C6-WROOM-1_EXP; MPN ESP32-C6-WROOM-1-N4
U6: TPS61040; WSON-6-1EP_2x2mm_P0.65mm_EP1x1.6mm_ThermalVias; MPN TPS61040DRVR
U7: IS31FL3730; QFN-24-1EP_4x4mm_P0.5mm_EP2.5x2.5mm; MPN IS31FL3730-QFLS2-TR
U8, U9: HCPL-354-06AE; SO-4_4.4x3.6mm_P2.54mm; MPN HCPL-354-06AE
U10: USBLC6-2SC6; SOT-23-6; MPN USBLC6-2SC6

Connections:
3V3: C1.1, C2.1, C5.1, C6.1, C7.1, C14.1, C15.1, R2.1, R3.1, R7.1, R13.1, R16.1, R18.1, R19.1, R32.1, R33.1, R39.2, R40.1, RS4.1, RS5.1, RS6.1, RS7.1, RS8.1, U2.1 (OUT), U5.2 (3V3), U7.3 (SDB), U7.11 (VCC)
3V3_PROBES: J8.3, J9.3, J10.3, J11.3, J12.3, R40.2
5V: C4.1, C9.1, D4.1 (K), D5.1 (K), L1.1, U2.4 (EN), U2.6 (IN), U6.2 (VIN), U6.3 (EN)
24V: C10.1, C11.1, C13.1, D6.1 (K), D7.1 (K), R10.1, R14.1, SW3.1
24V_FB: C13.2, R10.2, R11.1, U6.4 (FB)
24V_SW: D6.2 (A), L1.2, U6.6 (SW)
AUX1_DET: C16.1, R32.2, U5.19 (IO21), U9.4
AUX1_DRV: Q6.1, RL3.2
AUX1_EN: R20.1, RL3.1, U5.17 (IO19)
AUX1_IN: D18.2 (A2), J15.2, Q6.4, R22.1, R27.2
AUX1_OUT: D18.1 (A1), J15.1, Q6.3, R30.1, U9.2
AUX2_DET: C17.1, R33.2, U5.18 (IO20), U8.4
AUX2_DRV: Q7.1, RL4.2
AUX2_EN: R21.1, RL4.1, U5.16 (IO18)
AUX2_IN: D19.2 (A2), J15.4, Q7.4, R24.1, R29.2
AUX2_OUT: D19.1 (A1), J15.3, Q7.3, R31.1, U8.2
BOOT: C8.1, R7.2, SW1.1, U5.15 (IO9)
CC1: J13.A5 (CC1), R5.1
CC2: J13.B5 (CC2), R6.1
C_FILT: C20.1, U7.5 (C_FILT)
DET1_L: R23.2, U9.1
DET1_M: R22.2, R23.1
DET2_L: R25.2, U8.1
DET2_M: R24.2, R25.1
DISP_C1: DS1.10 (COL4), U7.24 (C1)
DISP_C2: DS1.11 (COL6), U7.23 (C2)
DISP_C3: DS1.13 (COL1), U7.22 (C3)
DISP_C4: DS1.15 (COL7), U7.21 (C4)
DISP_C5: DS1.16 (COL8), U7.19 (C5)
DISP_C6: DS1.3 (COL2), U7.18 (C6)
DISP_C7: DS1.4 (COL3), U7.17 (C7)
DISP_C8: DS1.6 (COL5), U7.16 (C8)
DISP_R1: DS1.14 (ROW2), U7.7 (R1)
DISP_R2: DS1.12 (ROW4), U7.8 (R2)
DISP_R3: DS1.9 (ROW1), U7.9 (R3)
DISP_R4: DS1.8 (ROW3), U7.10 (R4)
DISP_R5: DS1.7 (ROW6), U7.12 (R5)
DISP_R6: DS1.5 (ROW8), U7.13 (R6/C11)
DISP_R7: DS1.2 (ROW7), U7.14 (R7/C10)
DISP_R8: DS1.1 (ROW5), U7.15 (R8/C9)
EN: C3.1, R2.2, U5.3 (EN)
GND: C1.2, C2.2, C3.2, C4.2, C5.2, C6.2, C7.2, C8.2, C9.2, C10.2, C11.2, C12.2, C14.2, C15.2, C16.2, C17.2, C18.2, C19.2, C20.2, D7.2 (A), D8.1 (A1), D9.1 (A1), D10.1 (A1), D11.1 (A1), D12.1 (A1), D20.2 (A), D21.2 (A), J8.1, J9.1, J10.1, J11.1, J12.1, J13.A1 (GND), J13.A12 (GND), J13.B1 (GND), J13.B12 (GND), J13.SH (SHIELD), J14.2, Q3.2, Q4.2, Q5.4 (S), Q5.7 (S), Q6.2, Q7.2, R5.2, R6.2, R8.2, R9.2, R11.2, R20.2, R21.2, R30.2, R31.2, SW1.2, U1.14 (-Vo), U2.3 (GND), U2.7 (GND), U5.1 (GND), U5.28 (GND), U5.29 (GND), U5.30 (GND), U5.31 (GND), U5.32 (GND), U5.33 (GND), U5.34 (GND), U5.35 (GND), U5.36 (GND), U5.37 (GND), U6.1 (GND), U6.7 (GND), U7.4 (IN), U7.6 (AD), U7.20 (GND), U7.25 (GND), U8.3, U9.3, U10.2 (GND)
I2C_SCL: R19.2, U5.7 (IO7), U7.2 (SCL)
I2C_SDA: R18.2, U5.6 (IO6), U7.1 (SDA)
IO8: R3.2, U5.10 (IO8)
IO15: R39.1, U5.23 (IO15)
MAINS_L: F2.1, J3.1
MAINS_L_F: D2.2 (A2), D2.4 (A4), D3.2 (A2), D3.4 (A4), F2.2, Q3.4, Q4.4, R1.2, RS1.1, RS2.1, U1.1 (AC/L)
MAINS_N: J2.2, J3.2, R1.1, U1.3 (AC/N)
PE: C18.1, J3.3
PSU_5V: D4.2 (A), U1.16 (+Vo)
PUMP_FB: C12.1, R16.2, R17.1, U5.21 (IO23)
PUMP_FB_IN: D21.1 (K), J14.3, R17.2
PUMP_PWM: R12.1, U5.20 (IO22)
PUMP_PWM_G: Q5.3 (G), R12.2, R13.2
PUMP_PWM_LINE: Q5.1 (D), Q5.2 (D), Q5.5 (D), Q5.6 (D), Q5.8 (D), R14.2, R15.1
PUMP_PWM_OUT: D20.1 (K), J14.1, R15.2
Q1_G: D3.3 (G), RG3.2
Q2_G: D2.3 (G), RG4.2
RS1_m: CS1.1, RS1.2
RS2_m: CS2.1, RS2.2
SSR_CLOSE: R9.1, RL2.1, U5.26 (IO3)
SSR_OPEN: R8.1, RL1.1, U5.27 (IO2)
TEMP_HX_A: R37.1, RS7.2, U5.5 (IO5)
TEMP_HX_A_CON: D11.2 (A2), J11.2, R37.2
TEMP_HX_B: R38.1, RS8.2, U5.4 (IO4)
TEMP_HX_B_CON: D12.2 (A2), J12.2, R38.2
TEMP_RETURN: R35.1, RS5.2, U5.9 (IO1)
TEMP_RETURN_CON: D9.2 (A2), J9.2, R35.2
TEMP_SOURCE: R36.1, RS6.2, U5.11 (IO10)
TEMP_SOURCE_CON: D10.2 (A2), J10.2, R36.2
TEMP_SUPPLY: R34.1, RS4.2, U5.8 (IO0)
TEMP_SUPPLY_CON: D8.2 (A2), J8.2, R34.2
U3_A: Q3.1, RL1.2
U3_o6: Q3.6, RG3.1
U4_A: Q4.1, RL2.2
U4_o6: Q4.6, RG4.1
USB_D+: J13.A6 (D+), J13.B6 (D+), U5.14 (IO13), U10.1 (I/O1), U10.6 (I/O1)
USB_D-: J13.A7 (D-), J13.B7 (D-), U5.13 (IO12), U10.3 (I/O2), U10.4 (I/O2)
VALVE_CLOSE: CS2.2, D2.1 (A1), J2.3
VALVE_OPEN: CS1.2, D3.1 (A1), J2.1
VBUS: C19.1, D5.2 (A), J13.A4 (VBUS), J13.A9 (VBUS), J13.B4 (VBUS), J13.B9 (VBUS), U10.5 (VBUS)
WET1_M: R26.2, R27.1
WET2_M: R28.2, R29.1
WET_24V: R26.1, R28.1, SW3.2

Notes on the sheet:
CLASS II (DOUBLE INSULATED) - PLASTIC ENCLOSURE, NO PROTECTIVE EARTH. U1 IRM-03-5 is an isolated 2-wire module with no FG pin; there is no exposed conductive part requiring protective bonding. J3.3 (PE) is an ISOLATED PASS-THROUGH terminal provided so the installer can land the incoming earth condu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
8x8 MATRIX DISPLAY
PUMP PWM & TACHO
24VAC AUX SURGE
24V BOOST
PUMP LINE SURGE
USB
AUX CHANNELS - 24V DRIVE & AC/CONTINUITY DETECT
1-WIRE PROBE PROTECTION (J8-J12)
MOUNTING
ESP32-C6 MCU
USB-C
TEMPERATURE SENSORS (1-Wire)
POWER - MAINS INPUT, 5V PSU, 3V3 RAIL
VALVE TRIAC DRIVE (230 V)

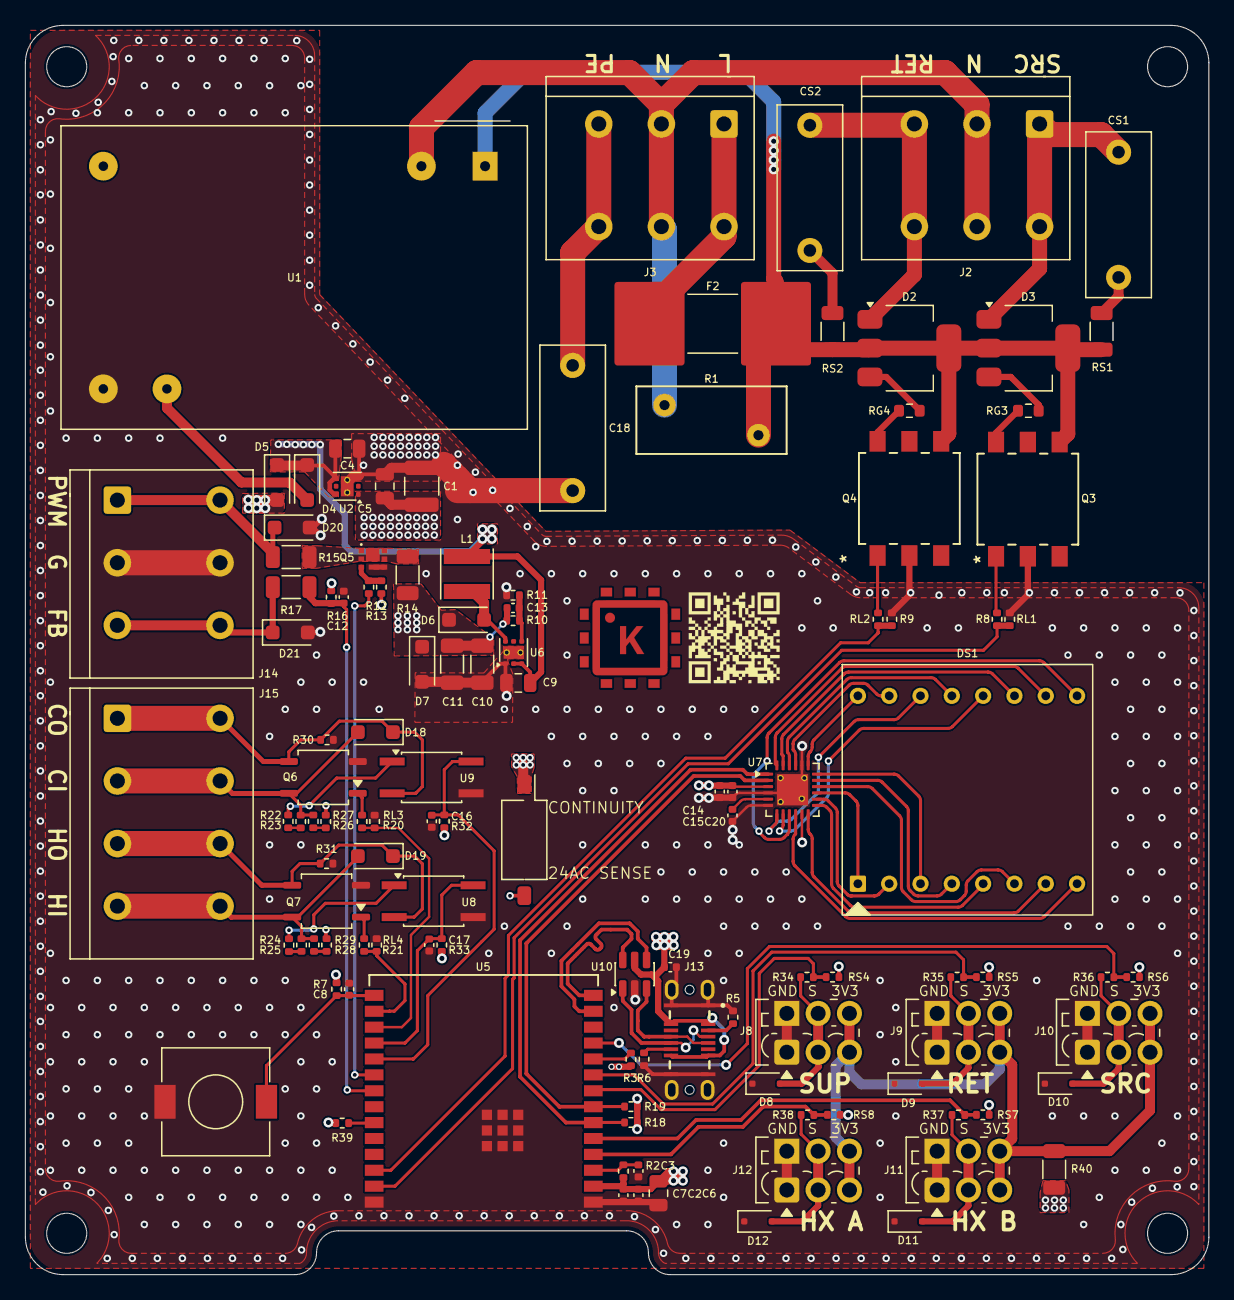
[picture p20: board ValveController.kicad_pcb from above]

Board: 4 copper layers, 94.5 x 99.8 mm, 123 parts (0 on the bottom side), 85 nets.

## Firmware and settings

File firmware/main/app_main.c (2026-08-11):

#include "freertos/FreeRTOS.h"
#include "freertos/task.h"
#include "driver/gpio.h"
#include "esp_log.h"
#include "console.h"
#include "config.h"
#include "sensors_hw.h"
#include "valve_hw.h"
#include "control_task.h"
#include "zigbee.h"
#include "ui.h"
#include "ota.h"
#include "taskhb.h"
#include <stdio.h>

#define PIN_SSR_OPEN   GPIO_NUM_2
#define PIN_SSR_CLOSE  GPIO_NUM_3
#define PIN_STAT_LED   GPIO_NUM_15   /* active-low: 0 = lit */

static const char *TAG = "app";

/* FIRST action in app_main: force both triacs off before anything else can run. */
static void triacs_safe_low(void)
{
    gpio_config_t io = {
        .pin_bit_mask = (1ULL << PIN_SSR_OPEN) | (1ULL << PIN_SSR_CLOSE),
        .mode = GPIO_MODE_OUTPUT,
        .pull_up_en = GPIO_PULLUP_DISABLE,
        .pull_down_en = GPIO_PULLDOWN_ENABLE,
        .intr_type = GPIO_INTR_DISABLE,
    };
    gpio_config(&io);
    gpio_set_level(PIN_SSR_OPEN, 0);
    gpio_set_level(PIN_SSR_CLOSE, 0);
}

void app_main(void)
{
    triacs_safe_low();                 /* MUST be first */
    hb_boot_report();                  /* before anything can overwrite the heartbeats */
    ESP_LOGI(TAG, "ValveController boot: triacs forced low");
    config_load();
    ota_init();
    sensors_start();
    valve_start();
    control_task_start();
    /* Restore the last state HA commanded. Forcing true here (the old "bench default")
     * meant that after any power blip the device regulated a live loop while the OnOff
     * attribute -- and therefore HA -- still read OFF. Must run BEFORE zigbee_start():
     * build_endpoints() seeds the OnOff attribute from control_task_water_running(). */
    control_task_set_water_running(config_water_running_load());
    zigbee_start();
    ui_start();
    console_start();
}

void console_hook_status(char *o, size_t n){
    sensor_reading_t s = sensors_get(SENS_SUPPLY), r = sensors_get(SENS_RETURN),
                     so = sensors_get(SENS_SOURCE), a = sensors_get(SENS_HX_A), b = sensors_get(SENS_HX_B);
    snprintf(o, n, "supply=%.2f ret=%.2f src=%.2f hxa=%.2f hxb=%.2f faults=%d%d%d%d%d\n",
             s.value_c, r.value_c, so.value_c, a.value_c, b.value_c,
             s.fault, r.fault, so.fault, a.fault, b.fault);
}

void console_hook_valve(int pct){ valve_set_target((float)pct); }
void console_hook_resync(void){ valve_resync(); }
void console_hook_factory_reset(void){ zigbee_leave(); config_factory_reset(); }

void zigbee_on_join(void){ ota_note_joined(); }

void console_hook_stats(char *o, size_t n){ sensors_format_stats(o, n); }

void console_hook_zbtemp(char *o, size_t n){ zigbee_format_temp_stats(o, n); }

void console_hook_hb(char *o, size_t n){ hb_format(o, n); }

void console_hook_mode(char *o, size_t n){
    const char *m = control_task_mode()==MODE_HEATING?"HEATING":
                    control_task_mode()==MODE_COOLING?"COOLING":"IDLE";
    snprintf(o, n, "mode=%s alarm=%d faults=0x%02x pos=%.1f\n",
             m, control_task_alarm(), control_task_faults(), valve_get_position());
}

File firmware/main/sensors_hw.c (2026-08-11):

#include "sensors_hw.h"
#include <stddef.h>
#include <stdio.h>
#include <stdlib.h>
#include <string.h>
#include "freertos/FreeRTOS.h"
#include "freertos/task.h"
#include "freertos/semphr.h"
#include "esp_attr.h"
#include "esp_timer.h"
#include "esp_log.h"
#include "esp_task_wdt.h"
#include "onewire_bus.h"
#include "onewire_crc.h"
#include "ctrl_core/sensor_policy.h"
#include "ctrl_core/diag_ring.h"
#include "taskhb.h"

static const char *TAG = "sensors";

/* GPIO per sensor id (spec §2): SUPPLY, RETURN, SOURCE, HX_A, HX_B.
 *
 * HX_A and HX_B are intentionally SWAPPED relative to spec §2 (HX_A reads GPIO19,
 * HX_B reads GPIO18) because the PCB layout swapped the HX-A/HX-B connectors
 * relative to the schematic. This mapping is correct for the fabricated board and
 * must NOT be reverted. Matters beyond labelling: mode detection keys off HX_A, so
 * without this swap heating/cooling selection would follow the wrong probe. */
static const int PIN[SENS_COUNT] = { 0, 1, 10, 19, 18 };
#define SWEEP_PERIOD_MS 10000
#define CONVERT_MS       750
#define MAX_RETRY          3
#define EMA_TAU_S       40.0f
/* Belt-and-braces for a sweep that stops producing readings without failing them
 * (task starved, RMT wedged, sweep_task deleted). Independent of the latch state:
 * a reading whose last good sweep is older than this is reported faulted, so control
 * degrades to park instead of silently integrating frozen data. 3 sweep periods plus
 * 5 s of slack. */
#define SENSOR_STALE_MS (3u * SWEEP_PERIOD_MS + 5000u)   /* 35 s */

/* DS18B20 ROM/function commands (Skip ROM: single sensor per wire). */
#define CMD_SKIP_ROM  0xCC
#define CMD_CONVERT_T 0x44
#define CMD_READ_SCR  0xBE

/* ---- Failure attribution -------------------------------------------------
 * onewire_read_temp() used to collapse six unrelated failures into a bare
 * `return false`, which is what made an intermittent field fault
 * undiagnosable: RMT exhaustion, an electrically absent probe, line noise and
 * a convert window that ran short all look identical from the sweep loop, yet
 * each has a different fix. Count them apart.
 *
 * The tallies live in RTC_NOINIT_ATTR to defeat an observability trap on this
 * board: opening the USB-JTAG port resets the chip (rst:0x15 USB_UART_HPSYS,
 * reproduced 5/5), so attaching a console to inspect a misbehaving run is the
 * one action guaranteed to destroy the run being inspected. RTC RAM survives
 * that warm reset, so sensors_start() can print the PREVIOUS run's tally --
 * plugging the cable in then yields the history you attached it to get. A true
 * power-on leaves the region uninitialised, which the magic detects. */
typedef enum {
    OW_OK = 0, OW_BUS, OW_RESET, OW_WRITE, OW_READ, OW_CRC, OW_POR, OW_REASONS
} ow_reason_t;

/* Indexed by ow_reason_t. "por85" is the DS18B20 power-on scratchpad (85.0 C):
 * the part answered fine but its conversion had not finished, which indicts
 * CONVERT_MS rather than the wiring -- the one failure here that is a firmware
 * timing bug rather than a plant problem. */
static const char *const OW_REASON[OW_REASONS] = {
    "ok", "rmt", "reset", "write", "read", "crc", "por85"
};
static const char *const SENS_NAME[SENS_COUNT] = {
    "supply", "return", "source", "hx_a", "hx_b"
};

/* 0x5EA5C0E0, bumped from 0x5EA5C0DF: the store gained a diag_hdr_t at the front, so
 * RTC contents written by 1.6.x no longer describe this layout. */
#define SENSOR_STATS_MAGIC 0x5EA5C0E0u

typedef struct {
    uint32_t sweeps;
    uint32_t ok[SENS_COUNT];
    uint32_t convert_fail[SENS_COUNT];
    uint32_t fail[SENS_COUNT][OW_REASONS];   /* [OW_OK] stays zero */
} sensor_stats_t;

typedef struct {
    diag_hdr_t     hdr;                          /* MUST be first */
    sensor_stats_t cur;
    sensor_stats_t hist[DIAG_RING_DEPTH];        /* hist[0] = most recently ended run */
} sensor_store_t;

_Static_assert(offsetof(sensor_store_t, hdr) == 0, "diag_hdr_t must be the first member");

static RTC_NOINIT_ATTR sensor_store_t s_store;
#define s_stats (s_store.cur)

static sensor_reading_t     g_read[SENS_COUNT];
static sensor_fault_state_t g_fault_state[SENS_COUNT];
static sensor_sweep_state_t g_sweep;      /* guarded by g_lock, like g_read */
static SemaphoreHandle_t    g_lock;

static ow_reason_t onewire_convert(int gpio)
{
    onewire_bus_handle_t bus = NULL;
    onewire_bus_config_t bcfg = { .bus_gpio_num = gpio };
    onewire_bus_rmt_config_t rmt = { .max_rx_bytes = 10 };
    if (onewire_new_bus_rmt(&bcfg, &rmt, &bus) != ESP_OK) return OW_BUS;
    ow_reason_t r = OW_OK;
    if (onewire_bus_reset(bus) != ESP_OK) r = OW_RESET;
    if (r == OW_OK) {
        uint8_t cmd[2] = { CMD_SKIP_ROM, CMD_CONVERT_T };
        if (onewire_bus_write_bytes(bus, cmd, 2) != ESP_OK) r = OW_WRITE;
    }
    onewire_bus_del(bus);      /* release the RMT pair for the next GPIO */
    return r;
}

static ow_reason_t onewire_read_temp(int gpio, float *out, uint16_t *raw_out)
{
    onewire_bus_handle_t bus = NULL;
    onewire_bus_config_t bcfg = { .bus_gpio_num = gpio };
    onewire_bus_rmt_config_t rmt = { .max_rx_bytes = 10 };
    if (onewire_new_bus_rmt(&bcfg, &rmt, &bus) != ESP_OK) return OW_BUS;
    ow_reason_t r = OW_OK;
    if (onewire_bus_reset(bus) != ESP_OK) r = OW_RESET;
    uint8_t scr[9] = {0};
    if (r == OW_OK) {
        uint8_t cmd[2] = { CMD_SKIP_ROM, CMD_READ_SCR };
        if (onewire_bus_write_bytes(bus, cmd, 2) != ESP_OK) r = OW_WRITE;
    }
    if (r == OW_OK && onewire_bus_read_bytes(bus, scr, 9) != ESP_OK) r = OW_READ;
    onewire_bus_del(bus);
    if (r != OW_OK) return r;
    if (onewire_crc8(0, scr, 8) != scr[8]) return OW_CRC;
    uint16_t raw = (uint16_t)((scr[1] << 8) | scr[0]);
    /* Folded in from the sweep loop so a never-converted part is attributed like
     * any other failure instead of disappearing into the retry condition. */
    if (sensor_fault_is_por_raw(raw)) return OW_POR;
    *raw_out = raw;
    *out = (int16_t)raw / 16.0f;                            /* 12-bit */
    return OW_OK;
}

static void apply_ema(sensor_id_t id, float v)
{
    float dt = SWEEP_PERIOD_MS / 1000.0f;
    float alpha = dt / (EMA_TAU_S + dt);                   /* ~0.2 at 10 s / 40 s */
    bool filtered = (id == SENS_SOURCE || id == SENS_RETURN);
    xSemaphoreTake(g_lock, portMAX_DELAY);
    bool just_cleared = sensor_fault_update(&g_fault_state[id], true);
    bool reseed = !filtered || just_cleared || g_read[id].last_ok_ms == 0;
    g_read[id].value_c = v;
    g_read[id].value_filt_c = sensor_ema_step(g_read[id].value_filt_c, v, alpha, reseed);
    g_read[id].last_ok_ms = (uint32_t)(esp_timer_get_time() / 1000);
    g_read[id].fault = g_fault_state[id].faulted;
    xSemaphoreGive(g_lock);
}

static void mark_fail(sensor_id_t id)
{
    xSemaphoreTake(g_lock, portMAX_DELAY);
    sensor_fault_update(&g_fault_state[id], false);
    g_read[id].fault = g_fault_state[id].faulted;
    xSemaphoreGive(g_lock);
}
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

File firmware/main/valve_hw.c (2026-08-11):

#include "valve_hw.h"
#include "config.h"
#include <stdlib.h>
#include "esp_log.h"
#include "freertos/FreeRTOS.h"
#include "freertos/task.h"
#include "freertos/semphr.h"
#include "driver/gpio.h"
#include "esp_timer.h"
#include "esp_task_wdt.h"
#include "ctrl_core/interlock.h"
#include "ctrl_core/pos_estimator.h"
#include "ctrl_core/resync_policy.h"
#include "taskhb.h"

static const char *TAG = "valve";

#define PIN_OPEN  GPIO_NUM_2
#define PIN_CLOSE GPIO_NUM_3
#define TICK_MS   100
#define RESYNC_STALL_MULT 1.15f

typedef enum { RS_IDLE, RS_DRIVING } resync_state_t;

static interlock_state_t s_ilk;
static pos_est_state_t   s_pos;
static SemaphoreHandle_t s_lock;
static float             s_target = 50.0f;
static resync_state_t    s_rs = RS_IDLE;
static uint32_t          s_rs_start_ms = 0;
static bool              s_resync_req = false;
static resync_policy_state_t s_rspol;
static bool               s_gate_ok = false, s_gate_hard = true;   /* boot default recirc-only until control publishes */
static bool               s_rs_toward_src = false;
static uint32_t            s_rs_extra_ms = 0;
/* Latched copies of the motion-affecting config, refreshed only while idle (see
 * valve_task), so a runtime config change never flips the open/close mapping, rescales
 * the stall/position math mid-stroke or mid-resync, nor moves the stop criterion under a
 * stroke already in progress. */
static bool              s_swap_latched = false;
static uint32_t          s_travel_latched_s = 0;
static float             s_deadband_latched = 1.0f;

static uint32_t now_ms(void){ return (uint32_t)(esp_timer_get_time() / 1000); }

/* Resolve which physical direction moves toward source(100)/recirc(0) via the latched swap. */
static valve_dir_t dir_toward_source(void){ return s_swap_latched ? VALVE_CLOSE : VALVE_OPEN; }
static valve_dir_t dir_toward_recirc(void){ return s_swap_latched ? VALVE_OPEN : VALVE_CLOSE; }

static int8_t travel_sign_of(valve_dir_t applied){
    if (applied == dir_toward_source()) return +1;
    if (applied == dir_toward_recirc()) return -1;
    return 0;
}

static void apply(triac_cmd_t c){
    /* Interlock guarantees never-both; this is the only writer of GPIO2/3. */
    gpio_set_level(PIN_OPEN,  c.open_on ? 1 : 0);
    gpio_set_level(PIN_CLOSE, c.close_on ? 1 : 0);
}

static valve_dir_t desired_dir(float target){
    float pos = s_pos.position_pct;
    if (target > pos + s_deadband_latched) return dir_toward_source();
    if (target < pos - s_deadband_latched) return dir_toward_recirc();
    return VALVE_STOP;
}

static void valve_task(void *arg){
    ESP_ERROR_CHECK(esp_task_wdt_add(NULL));
    for (;;) {
        esp_task_wdt_reset();
        hb_note(HB_VALVE);
        uint32_t t = now_ms();
        xSemaphoreTake(s_lock, portMAX_DELAY);

        if (s_rs == RS_IDLE){
            if (s_resync_req){                       /* boot + manual valve_resync(): forced recirc */
                s_rs = RS_DRIVING; s_rs_toward_src = false; s_rs_start_ms = t; s_resync_req = false;
                s_rs_extra_ms = 0;
            } else {
                resync_action_t act = resync_policy_step(&s_rspol, pos_est_needs_resync(&s_pos),
                                                         s_gate_ok, s_pos.position_pct, t);
                if (act != RESYNC_ACT_NONE){
                    s_rs = RS_DRIVING;
                    s_rs_toward_src = (act == RESYNC_ACT_START_SOURCE);
                    s_rs_start_ms = t;
                    s_rs_extra_ms = 0;
                }
            }
        }

        valve_dir_t want;
        if (s_rs == RS_DRIVING){
            /* Direction toward source is gated on comfort (s_gate_ok/s_gate_hard, set via
             * valve_note_resync_gate from control_step's resync_src_ok/hard_fail) --
             * see docs/superpowers/specs/2026-08-05-gated-bidirectional-resync-design.md */
            if (resync_policy_mid_stroke_abort(s_rs_toward_src, s_gate_hard)){
                s_rs_toward_src = false; s_rs_start_ms = t;
                /* Deadline extended by the interlock reversal blackout: interlock finishes
                 * the source pulse, stops, then anti-dithers before recirc drive begins. */
                s_rs_extra_ms = INTERLOCK_MIN_PULSE_MS + INTERLOCK_DEAD_TIME_MS + INTERLOCK_ANTI_DITHER_MS;
            }
            uint32_t stall_ms = (uint32_t)(s_travel_latched_s * 1000.0f * RESYNC_STALL_MULT) + s_rs_extra_ms;
            if (t - s_rs_start_ms >= stall_ms){
                pos_est_resync_done(&s_pos, s_rs_toward_src ? 100.0f : 0.0f);
                s_rs = RS_IDLE;
                want = VALVE_STOP;
            } else {
                want = s_rs_toward_src ? dir_toward_source() : dir_toward_recirc();
            }
        } else {
            want = desired_dir(s_target);
        }

        triac_cmd_t c = interlock_step(&s_ilk,
                                       want == VALVE_OPEN,  want == VALVE_CLOSE, t);
        apply(c);

        valve_dir_t applied = c.open_on ? VALVE_OPEN : (c.close_on ? VALVE_CLOSE : VALVE_STOP);

        /* Idle (not driving, not mid-resync): the only safe point to pick up config
         * changes for the *next* motion. While actually moving, both latches stay
         * frozen -- a travel_time_s write mid-stroke would otherwise rescale the
         * position estimator's %-per-tick under it. */
        if (applied == VALVE_STOP && s_rs == RS_IDLE) {
            s_swap_latched     = g_config.t.direction_swap;
            s_travel_latched_s = g_config.t.travel_time_s;
            s_deadband_latched = g_config.t.valve_deadband_pct;
        }

        pos_est_update(&s_pos, travel_sign_of(applied), TICK_MS, (float)s_travel_latched_s);

        xSemaphoreGive(s_lock);
        vTaskDelay(pdMS_TO_TICKS(TICK_MS));
    }
}

void valve_start(void){
    s_lock = xSemaphoreCreateMutex();
    interlock_init(&s_ilk);
    pos_est_init(&s_pos);
    resync_policy_init(&s_rspol);
    s_swap_latched     = g_config.t.direction_swap;          /* initial latch at boot */
    s_travel_latched_s = g_config.t.travel_time_s;
    s_deadband_latched = g_config.t.valve_deadband_pct;
    s_resync_req = true;                                   /* boot resync */
    /* No valve task means the triacs never move again: targets are accepted and silently
     * discarded, which reads as a working controller driving a stuck valve. Abort. */
    if (xTaskCreate(valve_task, "valve", 4096, NULL, 6, NULL) != pdPASS) {
        ESP_LOGE(TAG, "xTaskCreate(valve) failed -- aborting for reset+rollback");
        abort();
    }
}

void valve_set_target(float pct){
    if (isnan(pct)) return;   /* defense in depth: also reachable from console, not just Zigbee */
    xSemaphoreTake(s_lock, portMAX_DELAY);
    s_target = ctrl_clampf(pct, 0.0f, 100.0f);
    xSemaphoreGive(s_lock);
}
float valve_get_position(void){
    xSemaphoreTake(s_lock, portMAX_DELAY);
    float p = s_pos.position_pct;
    xSemaphoreGive(s_lock);
    return p;
}
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

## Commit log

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2026-07-13 fix(sch): rewire D1 active-low, add SSR pull-downs, drop DBG labels
    - D1 was reverse-biased (pad1=cathode on driven net) and could never light;
    now 3V3 -> R4 -> anode, cathode -> GPIO15 (also defines JTAG strap high)
    - R8/R9 10k pull-downs on SSR_OPEN/SSR_CLOSE define triacs-off at reset
    - DBG_TX/DBG_RX labels removed (J15 dropped for good), pins NC-flagged
    - ERC hygiene: PWR_FLAGs on mains/5V nets, NC flags on unused GPIOs (94->82)
    - Netlist diff verified: only the intended topology changes
    [ValveController.kicad_sch]
2026-07-13 feat: ValveController firmware v1 — ESP32-C6 Zigbee mixing-valve controller
    Squash of feat/firmware (34 commits): pure-C control core (FF+PI+governor,
    mode detect, degradation ladder, alarm dwell) with 11 host test suites;
    IDF glue (5x DS18B20 pipelined 1-Wire, triac valve driver with interlock
    and resync SM, 10s control task); Zigbee router (6 endpoints, custom
    cluster, Z2M converter) with OTA rollback gating; bench checklist + docs.
    Review-passed; safety paths verified.
    [partitions.csv]
2026-07-14 chore(pcb): reorganize into pcb/ and consolidate 3D models
    Move the KiCad project into pcb/, flatten custom STEP models into pcb/3dmodels/ (rewriting the KIPRJMOD-relative model paths in the board and footprints), relocate manual .bak snapshots to git-ignore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
    [1770966.stp, 1990986.stp, 46205000000.stp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]
2026-07-25 fix(zigbee): send reports with HA profile id and repair join state
    Attribute reports went out with APS profile 0 because
    esp_zb_zcl_reporting_info_t.dst.profile_id was never set in any of the
    three reporting configs. Coordinators route profile 0 to the ZDO parser,
    which rejects the frame; this crashed Zigbee2MQTT into a watchdog restart
    loop every reporting cycle.
    Also in this file:
    - Take the stack lock in zigbee_steer()/zigbee_leave(). Both run in the
    button and console tasks, where esp_zb_* calls are not thread-safe and
    were silently dropped, making the short-press join gesture a no-op.
    - Fire the join hooks on DEVICE_REBOOT. A commissioned device that reboots
    never emits STEERING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
2026-07-25 fix(z2m): convert external converter to ESM
    Zigbee2MQTT 2.x loads external converters as ES modules, so the CommonJS
    require()/module.exports form never loaded. Without a definition the
    device fell back to generateDefinition(), appearing as a raw IEEE address
    with generic entities and probing attributes the firmware does not
    implement.
    Rename to .mjs to match the loader (and the sibling converter already
    deployed) and update the doc references.
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2026-07-25 feat(ota): add Zigbee OTA client transfer handler and image tooling
    The OTA cluster was declared in zigbee.c but nothing ever received an
    image: no ESP_ZB_CORE_OTA_UPGRADE_VALUE_CB_ID handler and no esp_ota_*
    writes anywhere. ota.c only implemented the post-boot half (rollback
    gating). This adds the transfer half.
    ota_zcl_handle() drives the client state machine: START opens the
    inactive slot with esp_ota_begin(), RECEIVE streams blocks through
    esp_ota_write(), FINISH ends the write, sets the boot partition and
    reboots; ABORT and every error path call esp_ota_abort() so the handle
    is never leaked.
    The stack strips the 56-byte ZCL OTA file header before handing over
    payloads but not the 6-b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
2026-07-27 fix(zigbee): report every Z2M property instead of null
    Temperatures, tunables, mode and water_running all read null in
    Zigbee2MQTT while the sensors themselves were fine — the USB console
    showed all five probes live with faults=00000. Four independent defects:
    - The exposes declared names (supply_temp, ...) so their *property*
    defaulted to supply_temp_2, but fz.temperature publishes temperature_2
    — a key nothing ever writes. Bind them with withProperty('temperature')
    before withEndpoint(). The same mismatch broke water_running, whose
    writes also never reached tz.on_off (it keys on 'state'); hand-rolled
    fz/tz for it, matching the existing fzAnalogOutput pattern.
    - The 14 custo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
2026-07-27 feat(zigbee): expose firmware build ID and date code
    Z2M showed "unknown" for the firmware build ID because SWBuildID (0x4000)
    and DateCode (0x0006) are optional Basic-cluster attributes that
    esp_zb_basic_cluster_create() does not declare — there was simply nothing
    to read. Populate both at runtime from the app descriptor so they can
    never drift from the flashed image.
    Z2M captures these during the interview, so an already-paired device
    needs bridge/request/device/interview before they appear.
2026-07-27 chore(pcb): add CUI UJ20 USB-C library and continue routing
    Adds the CUI UJ20-C-V-C-3-SMT-TR vertical USB-C part (symbol, footprint
    and STEP) as a project-local library, registered through a new
    sym-lib-table plus an extra fp-lib-table entry. The board still places the
    GCT USB4115-03-C on J13 — the UJ20 is available but not swapped in yet.
    Also re-saves the PCB with incremental routing (405 -> 413 track/via
    elements) and picks up a reordered used_designators list, now including J1.
    [UJ20-C-V-C-3-SMT-TR.step, ValveController.kicad_pcb]
2026-07-27 chore(sensors): swap HX-A/HX-B GPIOs to match bench wiring
    The HX-B probe is currently plugged into the HX-A port, so HX_A now reads
    GPIO19 and HX_B reads GPIO18. This is not just a labelling concern: mode
    detection keys off HX_A, so without the swap heating/cooling selection
    would follow the wrong probe.
    Deliberately divergent from spec §2 and marked as such in the source —
    revert to { 0, 1, 10, 18, 19 } once the probes move to their correct ports.
    [sensors_hw.c]
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2026-07-30 fix(ctrl): clamp PI trim to ±20 % with integrator back-calculation
2026-07-30 fix(fw): validate/clamp v2 NVS load, reorder zigbee attrs, echo clamped tunables to ZCL
2026-07-30 fix(fw): validate loaded config, log fallbacks, order custom attrs, echo clamped writes
2026-07-30 fix(ctrl): clamp replayed transit-hold trim to current strategy authority
2026-07-31 fix(fw): reject NaN and bound all Zigbee-writable tunables and valve override
    [valve_hw.c]
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2026-07-31 fix(fw): governor-safe bounds, complete clamp echo-back, no-op write elision
    Governor trip thresholds (gov_high/gov_low) could previously be set inside
    the hardcoded 35/17 release band in control_task.c, causing the governor to
    limit-cycle. Bounds are now gov_high [35,60] / gov_low [0,17] in config.c
    (clamp_config + config_apply_custom) and config_map.c (tunable_apply).
    zigbee.c's attr_cb echo-back was incomplete: only 5 of 11 clamped/NaN-rejected
    custom-cluster attrs were echoed back into the ZCL attribute store after
    config_apply_custom() clamped them, so a subsequent read could diverge from
    the real g_config value. Added the missing heat_threshold, cool_threshold,
    gov_high, gov_low, trav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
2026-07-31 fix(fw): harden sensor faults and FF no-authority behavior; release 1.2.0
    - reject DS18B20 85.0 C power-on-reset reads (raw 0x0550) as failed reads
    - debounce fault clearing: 3 consecutive good sweeps to clear, single good
    read no longer resets the fail streak, boot starts latched-faulted
    - re-seed the EMA from the first trusted reading when a fault clears
    (new host-tested ctrl_core module: sensor_policy)
    - feed-forward: park at park_pos after 60 s of lost mixing authority
    instead of latching the last position; PI/transit-hold reset while parked
    - clamp gov_high >= 36 / gov_low <= 16, strictly outside the hardcoded
    35/17 governor release band, in firmware and the Z2M converter
    - docu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
    [sensor_policy.h, sensors_hw.c]
2026-07-31 fix(fw): leaky fault-streak decay, OTA gate decoupled from probes; release 1.2.1
2026-07-31 fix(fw): hold supply freeze alarm while the supply probe is faulted
2026-07-31 fix(fw): require 3 consecutive goods to decay a fault streak (25% break-even)
    [sensor_policy.h]
2026-07-31 fix(fw): latch travel_time_s with the direction swap so mid-stroke writes can't corrupt position
    [valve_hw.c]
2026-07-31 fix(fw): track inbound ZCL traffic as link liveness; mark cross-task state volatile
2026-07-31 fix(fw): persist water_running in NVS and seed the OnOff attribute from it
    [app_main.c]
2026-07-31 fix(fw): watchdog the sensor sweep, fault stale readings, snapshot faults under one lock
    [sensors_hw.c, valve_hw.c]
2026-07-31 fix(fw): publish ZCL invalid sentinel 0x8000 for faulted temperature probes
2026-07-31 fix(fw): echo clamped thermostat setpoints back to the attribute store, elide no-op saves
2026-07-31 docs(fw): release 1.3.0 — review-findings fixes
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2026-07-31 feat(fw): valve deadband tunable 0x0012 with travel-derived floor; RunningMode push
    Motor stop deadband (was fixed DEADBAND_PCT 2.0f) becomes config_t.valve_deadband_pct,
    exposed on custom cluster 0xFC00 as attr 0x0012, default 1.0 %, clamped to
    [max(0.2, 1.2*(INTERLOCK_MIN_PULSE_MS/1000)*100/(2*travel_time_s)), 5.0] — the floor
    keeps the band wider than half the interlock's min-pulse motion quantum, below which
    the motor limit-cycles (verified by simulation). travel_time_s writes re-clamp and
    re-echo the deadband. NVS blob migrates v2->v3 field-by-field (a prefix memcpy would
    land v2's cfg_version bits in the new float), preserving all stored tunables.
    Thermostat RunningMode (0x001E) now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
    [valve_hw.c]
2026-07-31 feat(z2m): valve deadband expose, hvacThermostat bind, ZHC-26 runningMode poll
    Adds the 0x0012 valve_deadband_pct tunable expose and a withValueStep(0.05) on
    pi_deadband_k (HA's default step of 1.0 over a 0-1 range only allowed 0 or 1).
    configure() now binds hvacThermostat on EP1 — live binding-table inspection showed
    it was never bound, so RunningMode reports had nowhere to go; this was the root
    cause of the mode sensor going stale for hours. A 5-minute runningMode poll (ZHC
    25+ single-event-object onEvent contract, globalStore-keyed self-rescheduling
    setTimeout chain) covers pre-1.4.0 firmware and missed pushes.
2026-07-31 docs(fw): release 1.4.0 — valve deadband tunable + RunningMode delivery fixes
2026-08-04 feat(fw): release 1.5.0 — setpoint-derived FF authority floor; hold instead of open-loop park
    Live GF-HydroMix telemetry showed the valve dropping to ~22 % for ~90 s at a time.
    Root cause: the setpoint-derived authority floor made the FF low-authority freeze
    reachable at a 19 C cooling setpoint (floor 3.51 K vs 2.79 K at 20 C, plant runs
    3.31-6.75 K), and a sustained freeze escalated to an open-loop park at park_pos.
    Replaying the freeze predicate over 3 h 13 m of telemetry predicted exactly two
    parks >= the dwell; exactly two were observed, with no false positives in 2316
    samples.
    - ff_step park_requested now HOLDS the current valve position instead of driving
    park_pos, and no longer r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
    [app_main.c]
2026-08-04 fix(fw): 1.5.1 — limit the FF denominator instead of freezing; coupling sign was inverted
    1.5.0 broke cooling on the live plant. On 2026-08-04 the valve sat at 55.7 % for
    92 minutes while supply ran 2.6-2.75 K above an 18.5 C setpoint and the house
    stopped being cooled. Root-caused from 869 Z2M samples (09:00-10:33).
    Three compounding defects:
    - pi.c's `if (freeze) return clampf(pos_ff, ...)` discards BOTH P and I, and
    control.c passed `freeze_pi || ff.frozen`. A low-authority FF therefore handed
    the valve a bare frozen constant and ran open-loop, ignoring t_supply — a
    perfectly valid measurement whatever the FF's denominator is doing.
    - The derived floor reached 4.0 K (clamped)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
2026-08-05 fix(pcb): CS1/CS2 snubber 22nF X2 -> 4.7nF X1 (ECQ-UBAF472V5, actuator hum)
    [ValveController.kicad_sch]
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2026-08-05 fix(fw): extend aborted resync stroke by interlock reversal blackout
    [valve_hw.c]
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2026-08-05 feat(pcb): 24V boost leaf (TPS61040) for pump iPWM interface
    Add TPS61040DRVR (WSON-6) 5V->24V boost converter block for the Wilo
    Para ST 15-7-50 iPWM2 drive input: U6 (TPS61040DRVR), L1 (10uH boost
    inductor), D6 (B5819W rectifier), C9 (input cap), C10/C11 (output
    caps), R10/R11 (1M/53.6k FB divider, Vout~=24.2V), C13 (22pF
    feedforward cap across R10 per TI datasheet reference design).
    New nets: 24V, 24V_SW, 24V_FB. Grows 5V and GND per plan. U6 pin 5
    (NC) explicitly flagged with a no-connect marker.
    ERC: zero new errors, zero new violation categories; +8 warnings are
    all pre-existing lib_symbol_issues (one per new R_dev/C_dev/L_dev/
    Kleist-style symbol, matching every other passive alread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
    [ValveController.kicad_sch]
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2026-08-05 fix(pcb): 24V rail Zener clamp, FB divider rescale, R16 10k, Q5 pin7 name (final review)
    [ValveController.kicad_sch]
2026-08-05 docs(pcb): failsafe matrix corrections, D7 clamp, 500 Hz PWM, mis-plug notes (final review)
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2026-08-05 fix(pcb): CS1/CS2 snubber part swap for next spin — EOL ECQ-UBAF472V5 -> KEMET R413F147050T1K (X1/Y2 300VAC, 10mm footprint)
    [ValveController.kicad_sch]
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2026-08-05 fix(pcb): correct 8x8 matrix footprint row spacing 5.9mm -> 15.0mm
    Datasheet side-view dimension "15 [5.910]" is the pin-row spacing;
    5.9mm is the package body depth, not the lead spread. Move all 16
    pads from y=+/-2.95 to y=+/-7.5 (per Luckylight W07088A/B p.3 and
    corroborating KWM-20881ARGA-G5M drawing). X pitch/span and pin
    diameter were already correct and are untouched.
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2026-08-05 docs(pcb): resolve display/aux MPN open items
2026-08-05 docs(pcb): remove stale placeholder text from resolved circuit tables
2026-08-05 fix(pcb): un-mirror 8x8 matrix footprint pad rows (pin1 bottom-left)
    DS1's LED_Matrix_8x8_20mm footprint had pads 1-8 and 9-16 assigned to
    the wrong rows: pads 1-8 sat at y=-7.5 (top row) and 9-16 at y=+7.5
    (bottom row), the vertical mirror of the datasheet face view
    (kwm20881-single.pdf p.3, corroborated by KWM-20881ARGA.pdf p.2), which
    shows PIN1 bottom-left, PIN8 bottom-right, PIN9 top-right, PIN16
    top-left. Left uncorrected, all 16 display nets would land on the
    physically wrong pin.
    Swapped the y sign of every pad and moved the pin-1 silk marker to the
    new bottom-left location of pad 1. Courtyard/silk/fab outlines are
    unchanged (they are already symmetric about the origin).
2026-08-05 fix(pcb): relocate display and aux blocks inside A3 sheet extents
    The Task-2 display block (U7/DS1/SW2/R18/R19/C14/C15, x=414.02-459.74)
    and Task-3 AUX block (R20/R21/RL3/RL4/Q6/Q7/J15, x=495.3-548.64) were
    placed beyond the A3 sheet's 420mm width, clipping out of plots/PDF
    exports entirely.
    Translated both blocks as rigid units (symbols + their properties +
    associated global labels) into surveyed free space inside the sheet:
    display block shifted by (-53.34, +39.37) to x=[360.68,406.4]
    y=[64.77,149.86]; AUX block shifted by (-234.95, -10.16) to
    x=[260.35,313.69] y=[10.16,58.42]. Both deltas are exact multiples of
    1.27mm to preserve the schematic grid. Pre-existing content (x up to
    398.78,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
    [ValveController.kicad_sch]
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2026-08-05 docs(pcb): SW1-only button semantics — page cycle, 10s factory reset, auto-steer
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2026-08-05 fix(pcb): J14 pump terminal to SPT 2,5/3-H-5,0 (1990986), matching J2/J3
    [ValveController.kicad_sch]
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2026-08-05 fix(pcb): U8 MPN to LTV-824S — tape variant out of stock, tube in stock
    [ValveController.kicad_sch]
2026-08-06 docs(pcb): design spec for status-LED strip and USB4145 connector swap
2026-08-06 feat(pcb): strip status LED, USB4145 connector, reorganise schematic
    The 8x8 matrix display (DS1 + U7) supersedes the D1 status LED, so D1 goes
    along with R4, its GPIO15 strap pull-up — GPIO15 is Ignored with the default
    eFuses, leaving it and GPIO16 as the only clean non-strapping spares.
    J13 swaps from GCT USB4115 to USB4145-03-0170-C: easier to hand-solder, no
    shield tabs in front of the pins. The SnapMagic-derived footprint and STEP
    are gitignored — their licence permits building boards, not redistributing
    model files — so regenerate with tools/import_usb4145.py. The two hand-drawn
    peg keepouts are dropped; they were cut for the USB4115 body and fouled the
    new 1.15 mm contact row.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
    [UJ20-C-V-C-3-SMT-TR.step, ValveController.kicad_pcb, ValveController.kicad_sch]
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2026-08-10 fix(fw): blend the FF sign across the zero-authority band
    The mixing law divides by (t_src - t_ret), and `want` cannot change sign within
    a mode, so at low authority the measured sign of the denominator alone decided
    which rail the output clamped to. Clamping the denominator's MAGNITUDE to the
    floor while keeping that sign left a step discontinuity at denom = 0 the size of
    the whole output range: at t_ret 20.9 / t_set 18.5, t_src 20.89 gave 100 % and
    20.91 gave 0 %. Two readings 0.02 K apart, well inside what a pair of DS18B20s
    agree to.
    Live on 2026-08-08 the plant lost cooling output for ~4.5 h with dT parked
    inside +/-0.05 K. The FF chattered rail to rail, the 180 s output EMA turning it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
2026-08-10 feat(pcb): rework copper zones, add 3D models and design-check tools
    Zone work only on the layout -- outlines, priorities and one new zone. No
    footprints added or removed and no netlist change.
    Vendor 3D models for parts already on the board: 1770885 (PTSM 0,5/2-2,5-H, the
    split AUX blocks) and ECQUBAF472V5 (the 4.7 nF X1/Y2 snubber that replaced the
    22 nF part). board.step and top.stl regenerated to match.
    tools/display_map.py reads the U7 IS31FL3730 -> DS1 KWM-20881AGB mapping out of
    the schematic and PCB and checks the two agree, plus the source/sink rule that
    decides whether the common-row-anode part can light at all under DM=00 vs
    DM=01. Read-only: the design files stay the source of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
    [1770885.stp, ECQUBAF472V5.step, ValveController.kicad_pcb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]
2026-08-10 feat(fw): release 1.6.1 — continuous FF sign across zero authority
    Version bump and release notes for the feedforward sign-continuity fix in
    e30c941. Built and verified: PROJECT_VER reads 1.6.1 in the app descriptor
    (idf.py reconfigure first — the stale-PROJECT_VER trap), 705712 byte image,
    63 % of the OTA slot free, host suite 17/17.
    OTA fileVersion 0x01060100, which is strictly greater than the 1.5.1
    (0x01050100) actually running on the device.
2026-08-11 fix(fw): release 1.6.3 — sweep liveness, checked task creation, attr-write tally
    Incident 2026-08-10: the plant sat parked for 13 h after an OTA to 1.6.1, all five
    probe endpoints publishing the ZCL invalid sentinel from 19:11:32Z — the post-OTA
    reboot — until a reset was forced by hand. The device stayed joined, answered reads
    and accepted valve commands throughout.
    The 1-Wire bus was never at fault. `stats` after the reset showed zero read failures
    of any kind on any probe, and every probe returned a plausible temperature at once.
    1.6.1 changed only feedforward maths, which cannot latch a probe.
    Root cause of that outage is NOT identified. The per-reason failure tally lives in
    RTC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
    [app_main.c]
2026-08-11 fix(fw): keep 4 runs of attr-write history, add table read-back
    Reaching this board's console costs two resets: plugging the cable in is one, opening
    the port is another. A one-deep "previous run" is therefore destroyed before it can
    ever be read — the measurement consumes its own evidence.
    That has now happened twice. The 1-Wire tally for the 13 h outage on 2026-08-10 was
    lost that way, and the first cut of the attribute-write tally lost the 2026-08-11
    mains-only reproduction the same way, in the same session, after I had supposedly
    learned the lesson. Keep ZB_RUN_HISTORY=4 runs in RTC so two resets cannot reach the
    run under investigation, tagged with a boot sequence number so runs are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
    [sensors_hw.c]
2026-08-11 fix(fw): record the reset reason per run
    Measured 2026-08-11: the board resets roughly every 40 s on mains alone and runs
    indefinitely the moment USB is connected. Proof is the boot sequence counter — a
    mains-only power cycle to seq=1 was at seq=8 about three minutes later, with each run
    lasting 3-5 telemetry ticks, while a 120 s watch with USB attached produced exactly one
    boot, the one the console itself caused.
    That also explains the symptom this whole investigation started from, and rules the
    firmware out of it. In every captured run faults=0x00, every attribute write returns ok
    with mism=0, and the table reads back real temperatures (21.00, 20.87, 15.12, 14.50,
    14.87). Nothing is wro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
2026-08-11 fix(fw): per-task heartbeats in RTC to name the watchdog starver
    Two consecutive mains-only runs ended in TASK_WDT (boot=TASK_WDT on run#3 and run#4),
    so the ~40 s reboot loop is a watchdog timeout, not the brownout the USB correlation
    suggested. 30 s timeout plus boot time matches the observed period.
    The panic text names the offending task, but it goes to the console, and on this board
    the console is USB — whose presence is precisely what stops the resets. The name can
    therefore never be read at the moment it is produced. So record, per subscribed task,
    the uptime at its last loop iteration, in RTC RAM, and report it on the next boot. The
    stalest heartbeat is the task that stopped feedi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
    [app_main.c, sensors_hw.c, valve_hw.c]
2026-08-11 fix(fw): keep 4 runs of heartbeats, labelled by how each run died
    The first cut kept one previous run and so could not answer its own question. Reaching
    the console costs a reset, so the run you can read is always the one YOUR reset ended,
    never the one the fault ended: the readout came back with all four heartbeats fresh
    because it described run#4, killed by plugging the cable in, while the TASK_WDT run was
    run#3 and already overwritten.
    Same one-deep flaw as the 1-Wire tally and the attribute-write tally before it — third
    time in one investigation, on an observability trap this repo already documents in two
    other files.
    Ring of 4, and each entry now carries the reset reason observed at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
2026-08-11 fix(fw): release 1.6.4 — don't start the console REPL without a USB host
    Root cause of the 2026-08-10 "every probe is dead" outage. With no USB host attached
    the console REPL's reads return immediately instead of blocking, so its line-editing
    loop free-runs. It sits above the idle task (priority 0) and below the app tasks (4-6),
    so every watchdog-subscribed app task kept feeding on schedule while the idle task never
    got scheduled — and the idle task is a subscriber
    (CONFIG_ESP_TASK_WDT_CHECK_IDLE_TASK_CPU0=y). 30 s later, ESP_RST_TASK_WDT. Every ~40 s,
    indefinitely, but only when no USB host was attached.
    What named it: per-task heartbeats in RTC. The run labelled boot=TASK_WDT died at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
    [sensors_hw.c]
2026-08-11 refactor(fw): rebuild task heartbeats on the shared diag ring
    Also teach diag_reset_reason_name() this IDF's three reset reasons past
    the plan's table (EFUSE=13, PWR_GLITCH=14, CPU_LOCKUP=15) instead of
    letting them fall through to "other" -- this board's 1.6.x history was
    watchdog and power faults, exactly what those labels would identify.
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2026-08-12 docs(analysis): PCB layout design review 2026-08-12 — fab-ready after same-day fixes
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2026-08-12 docs: update README for fab-ready PCB and firmware 1.7.0
    Status blockquote, hardware table, repo layout, and documentation
    links were stale after the 4-layer layout completed (100% routed,
    DRC clean, boards ordered 2026-08-12) and firmware 1.7.0 shipped
    OTA on 2026-08-11. Also documents the pump-interface boost and AUX
    PhotoMOS channels that were missing from the hardware summary, and
    links the two design review reports.

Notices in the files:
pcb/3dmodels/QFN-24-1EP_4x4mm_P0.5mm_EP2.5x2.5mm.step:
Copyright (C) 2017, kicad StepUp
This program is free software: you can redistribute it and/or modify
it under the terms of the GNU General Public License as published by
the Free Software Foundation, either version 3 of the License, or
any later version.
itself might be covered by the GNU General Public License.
